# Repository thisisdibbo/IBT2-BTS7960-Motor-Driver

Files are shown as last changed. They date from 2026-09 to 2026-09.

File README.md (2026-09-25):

# IBT-2 High-Current H-Bridge Motor Driver (BTS7960B) — Custom PCB

<p align="center">
  
  
  
</p>

A custom-designed **IBT-2 style H-bridge motor driver** built around two Infineon **BTS7960B** high-current half-bridges and a **TI SN74HC244** input buffer. It drives one brushed DC motor in both directions, with PWM speed control from any microcontroller (Arduino, ESP32, STM32, …).

The board was designed in Autodesk EAGLE, then fabricated, assembled and bench-tested: **at full drive, the voltage across the motor terminals equals the supply voltage**, confirming that the H-bridge switches the full supply onto the load.

It also has a **built-in HAT circuit**: a red power LED, two green signal LEDs and a 4-pin JST connector that plugs straight into an Arduino shield PCB — see [Built-in HAT Circuit](#built-in-hat-circuit).

## Contents

- [Fabricated Board](#fabricated-board)
- [Schematic and PCB](#schematic-and-pcb)
- [Features](#features)
- [Built-in HAT Circuit](#built-in-hat-circuit)
- [How It Works](#how-it-works)
- [Pinout](#pinout)
- [Control Logic](#control-logic)
- [Quick Start (Arduino)](#quick-start-arduino)
- [Specifications](#specifications)
- [Test Results](#test-results)
- [Bill of Materials](#bill-of-materials)
- [Repository Structure](#repository-structure)
- [Limitations and Future Improvements](#limitations-and-future-improvements)
- [References](#references)
- [Author](#author)
- [License](#license)

---

## Fabricated Board

<!-- Put your two photos in the images/ folder with exactly these names: fabricated_1.jpg and fabricated_2.jpg -->
<p align="center">
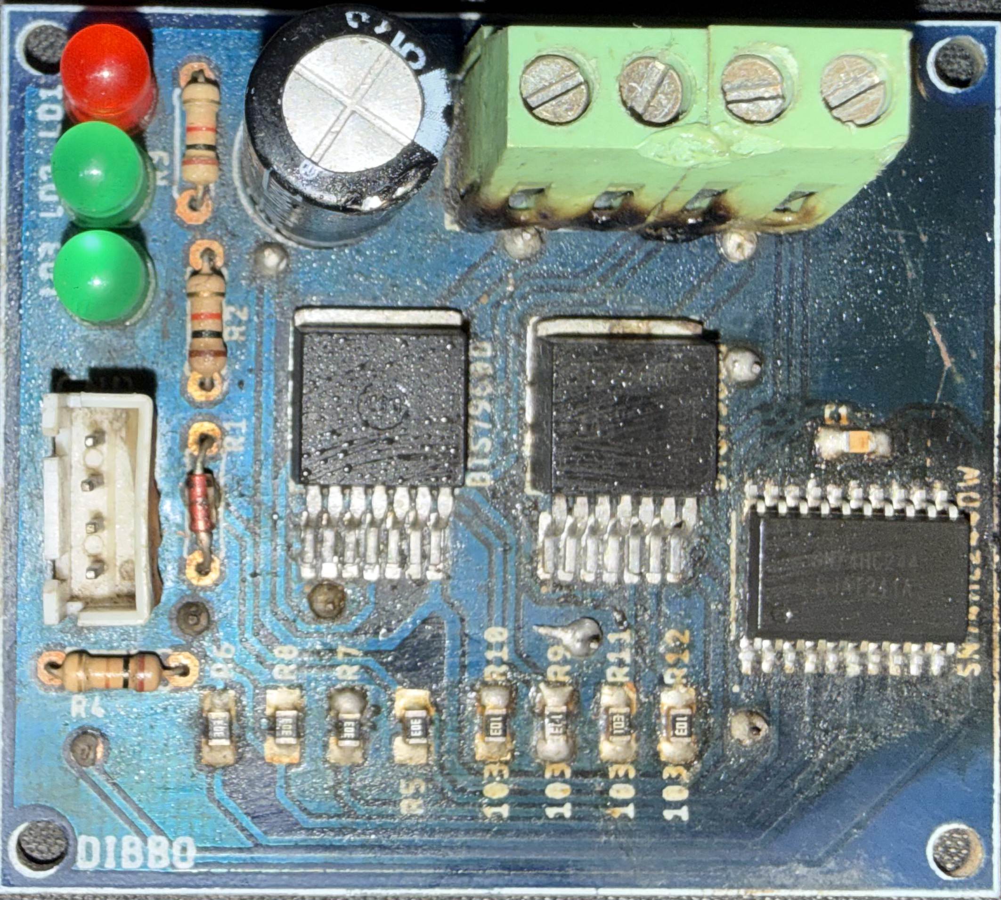
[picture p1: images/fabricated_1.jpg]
Fabricated IBT-2 board, photo 1
  
  &nbsp;&nbsp;
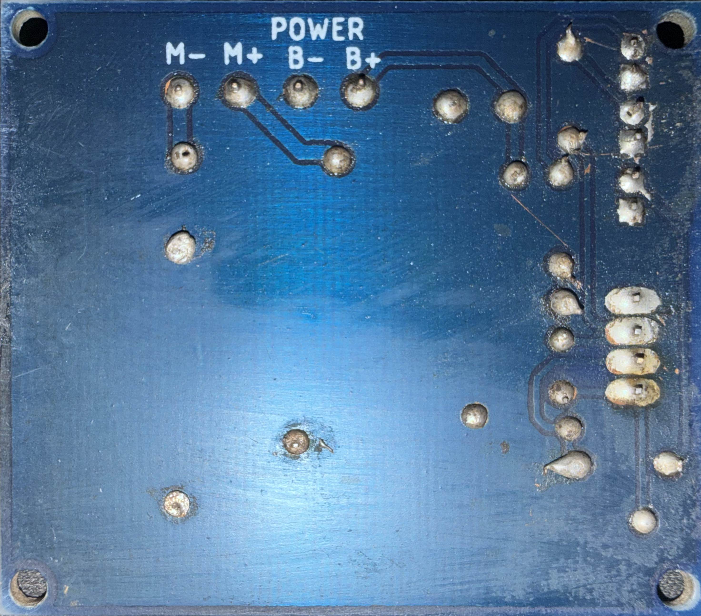
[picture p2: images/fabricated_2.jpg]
Fabricated IBT-2 board, photo 2
  
</p>
<p align="center"><em>The fabricated and assembled board</em></p>

## Schematic and PCB

<p align="center">
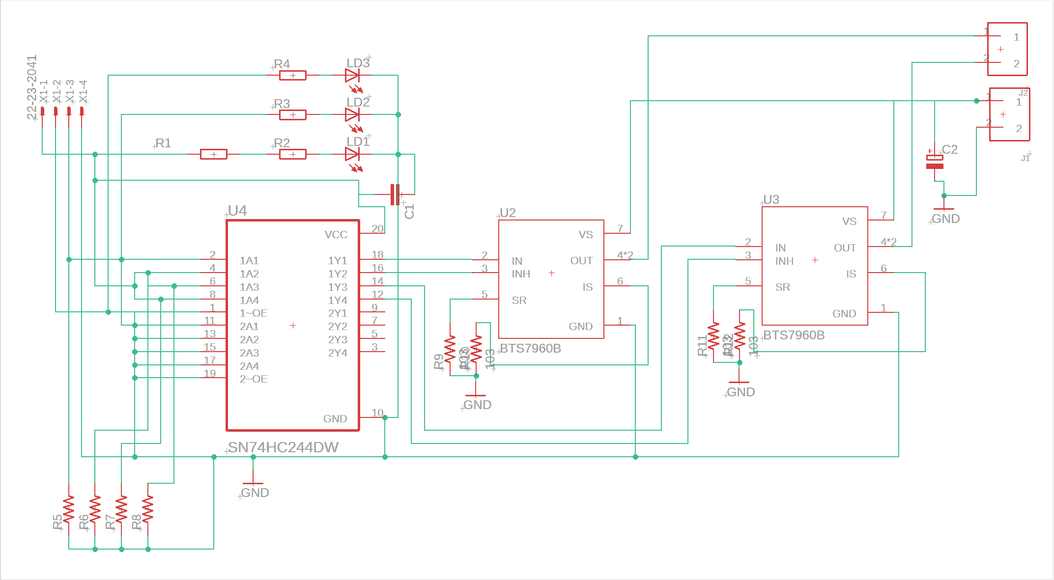
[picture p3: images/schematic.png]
Schematic of the IBT-2 motor driver
  
</p>
<p align="center"><em>Schematic — U4 buffers the inputs, U2 + U3 form the H-bridge, J1 = power in, J2 = motor out</em></p>

<p align="center">
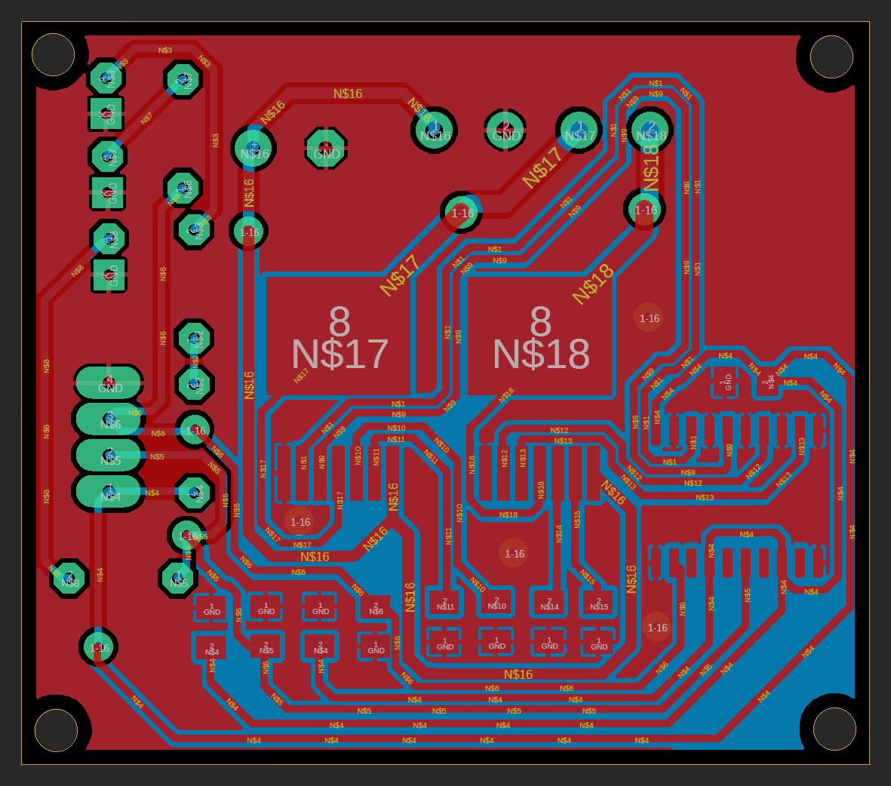
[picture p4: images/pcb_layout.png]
PCB layout of the IBT-2 motor driver
  
</p>
<p align="center"><em>PCB layout — 2 layers, 59.6 × 52.3 mm, red = top copper, blue = bottom copper, GND pour on both layers</em></p>

## Features

- **Full H-bridge** from two BTS7960B NovalithIC™ half-bridges (7 mΩ high-side + 9 mΩ low-side, typ.)
- **Buffered inputs** — an SN74HC244 sits between the microcontroller and the power stage
- **Only two control signals** (RPWM, LPWM) — both half-bridges are enabled automatically when logic power is present
- **Safe default state** — on-board 30 kΩ pull-downs hold RPWM/LPWM LOW if the MCU pins float (e.g. during reset), so the motor is held in brake instead of running
- **Built-in HAT circuit** — red power LED, two green signal LEDs and a 4-pin JST connector for direct connection to an Arduino shield PCB
- **Protection built into the BTS7960B** — current limitation, short-circuit and over-temperature shutdown, under-voltage shutdown, over-voltage lock-out
- **Adjustable slew rate** through the SR resistors (10 kΩ fitted)
- **Bulk capacitor** on the motor supply and a decoupling capacitor on the logic supply
- **5 mm screw terminals** for power and motor
- 4 × Ø3 mm mounting holes

## Built-in HAT Circuit

The logic side of the board is a small built-in **HAT circuit**: the driver plugs into an Arduino shield PCB with one cable, and its status can be read at a glance — no loose jumper wires.

| Part | Type | Function |
|:---:|:---|:---|
| LD1 | 🔴 Red LED, 3 mm | **Power ON** — lights when the logic supply (VCC) is present |
| R1 | Diode (on the R1 footprint) | **Reverse protection** — in series with the red power LED, protects the LED branch if VCC is connected backwards |
| LD2 | 🟢 Green LED, 3 mm | **RPWM signal** — lights when RPWM is HIGH (forward) |
| LD3 | 🟢 Green LED, 3 mm | **LPWM signal** — lights when LPWM is HIGH (reverse) |
| X1 | 4-pin JST connector | **Direct connection to the Arduino shield PCB** with a single JST cable (VCC, LPWM, RPWM, GND) |

The green LEDs are driven by the control signals themselves, so under PWM their brightness follows the duty cycle — direction and approximate speed are visible at a glance.

## How It Works

```mermaid
flowchart LR
    MCU["Arduino shield PCB<br/>or any MCU"] -->|RPWM, LPWM| X1["HAT circuit<br/>JST connector + LEDs"]
    X1 --> BUF["U4 · SN74HC244<br/>input buffer"]
    BUF -->|IN, INH| U2["U2 · BTS7960B<br/>half-bridge A"]
    BUF -->|IN, INH| U3["U3 · BTS7960B<br/>half-bridge B"]
    PSU["Motor supply<br/>B+ / B−"] --> U2
    PSU --> U3
    U2 -->|M+| MOT(("DC<br/>motor"))
    U3 -->|M−| MOT
```

- **Power stage** — each BTS7960B contains a high-side P-MOSFET, a low-side N-MOSFET and a gate driver with built-in dead-time. With INH HIGH, `IN = HIGH` connects the output to B+ and `IN = LOW` connects it to GND; INH LOW puts the chip to sleep. U2 drives **M+**, U3 drives **M−**, and the motor sits between them.
- **Input stage** — U4 buffers RPWM → U2 `IN` and LPWM → U3 `IN`. Two more U4 channels (1A2, 1A4) are tied to VCC, so both `INH` pins go HIGH as soon as logic power is applied. The unused second half of U4 has its inputs and output-enable tied to GND so nothing floats.
- **Slew rate and current sense** — R9/R11 (10 kΩ, SR → GND) give a moderate switching slew rate. The IS (current-sense / fault) pins are terminated with R10/R12 (10 kΩ) to GND and are not routed to the header in this revision.
- **Supply** — C2 (330 µF) is the bulk capacitor on B+, C1 (100 nF) decouples U4. A diode on the R1 footprint sits in series with the power-LED branch (X1-1 → R1 → R2 → LD1). Logic ground and power ground are the same net.

## Pinout

> The **B+ B− M+ M−** labels are printed on the **bottom** silkscreen. On X1, pin 4 (GND) is next to the **GND** mark on the top silkscreen.

### X1 — JST logic connector (4-pin, to the Arduino shield)

| Pin | Signal | Description |
|:---:|:---|:---|
| 1 | **VCC** | Logic supply for U4 — 5 V (or 3.3 V for 3.3 V MCUs). Also enables both half-bridges; red LED LD1 lights. |
| 2 | **LPWM** | Drives U3 → **M−**. HIGH = M− to B+, LOW = M− to GND. Green LED: LD3 |
| 3 | **RPWM** | Drives U2 → **M+**. HIGH = M+ to B+, LOW = M+ to GND. Green LED: LD2 |
| 4 | **GND** | Ground (same net as B−) |

### J1 — Power input (2-pin screw terminal, 5 mm)

| Pin | Label | Description |
|:---:|:---:|:---|
| 1 | **B+** | Motor supply V<sub>S</sub>, 5.5 – 27.5 V |
| 2 | **B−** | Supply ground |

### J2 — Motor output (2-pin screw terminal, 5 mm)

| Pin | Label | Description |
|:---:|:---:|:---|
| 1 | **M+** | Output of U2 (controlled by RPWM) |
| 2 | **M−** | Output of U3 (controlled by LPWM) |

> **Wiring:** always connect the microcontroller GND to X1-4. B− and X1-4 are the same ground.

## Control Logic

Both half-bridges are enabled whenever VCC is present (INH = HIGH).

| RPWM (X1-3) | LPWM (X1-2) | M+ | M− | Motor |
|:---:|:---:|:---:|:---:|:---|
| HIGH | LOW | B+ | GND | Forward, full speed (V<sub>out</sub> ≈ V<sub>in</sub>) |
| LOW | HIGH | GND | B+ | Reverse, full speed |
| PWM | LOW | PWM | GND | Forward, speed ∝ duty cycle |
| LOW | PWM | GND | PWM | Reverse, speed ∝ duty cycle |
| LOW | LOW | GND | GND | Brake (both low-side switches on) — also the default when the inputs float |
| HIGH | HIGH | B+ | B+ | Brake (both high-side switches on) |

> Bring the motor to a stop (both inputs LOW) before reversing direction.

## Quick Start (Arduino)

Plug the JST cable from the Arduino shield PCB into X1, or wire the pins directly:

| Driver | Connect to |
|:---|:---|
| X1-1 VCC | Arduino **5V** |
| X1-2 LPWM | Arduino **D6** |
| X1-3 RPWM | Arduino **D5** |
| X1-4 GND | Arduino **GND** |
| J1 B+ / B− | Motor power supply + / − |
| J2 M+ / M− | DC motor |

```cpp
// IBT-2 (BTS7960B) custom driver — bidirectional test
const uint8_t RPWM = 5;   // X1-3 -> M+
const uint8_t LPWM = 6;   // X1-2 -> M-

// speed: -255 (full reverse) ... 0 (brake) ... +255 (full forward)
void setMotor(int speed) {
  speed = constrain(speed, -255, 255);
  if (speed >= 0) {
    analogWrite(LPWM, 0);
    analogWrite(RPWM, speed);
  } else {
    analogWrite(RPWM, 0);
    analogWrite(LPWM, -speed);
  }
}

void setup() {
  pinMode(RPWM, OUTPUT);
  pinMode(LPWM, OUTPUT);
  setMotor(0);
}

void loop() {
  setMotor(255);  delay(2000);   // full forward: V(M+ - M-) ≈ +V_in
  setMotor(0);    delay(1000);   // brake
  setMotor(-255); delay(2000);   // full reverse: V(M+ - M-) ≈ -V_in
  setMotor(0);    delay(1000);
  setMotor(128);  delay(2000);   // about 50 % speed forward
  setMotor(0);    delay(1000);
}
```

**Notes**

- **3.3 V boards (ESP32, STM32, Pico):** power X1-1 (VCC) from **3.3 V**, not 5 V. With VCC = 5 V the 74HC244 needs about 3.5 V for a logic HIGH, which a 3.3 V pin may not reach reliably. The BTS7960B inputs only need ≥ 2.15 V, so 3.3 V logic is enough. *(3.3 V operation follows from the datasheets; not yet tested on this board.)*
- **Never power VCC above 5.3 V** — U4 passes VCC straight to the BTS7960B `IN`/`INH` pins, whose absolute maximum is 5.3 V.
- Arduino Uno PWM on D5/D6 runs at about 980 Hz, which can make the motor whine. The BTS7960B supports PWM up to 25 kHz.

## Specifications

| Parameter | Value |
|:---|:---|
| Motor supply V<sub>S</sub> (B+) | 5.5 – 27.5 V (BTS7960B operating range; undervoltage shutdown at 4.0 – 5.4 V, over-voltage lock-out at 27.6 – 30 V) |
| Logic supply (VCC) | 5 V nominal, 3.3 V for 3.3 V MCUs — max 5.3 V |
| Control inputs | RPWM, LPWM — active HIGH, 30 kΩ pull-down on each |
| Interface (HAT circuit) | 4-pin JST connector · red power LED · 2 green signal LEDs |
| PWM frequency | Up to 25 kHz |
| Switch on-resistance | 7 mΩ high-side + 9 mΩ low-side (typ. at 25 °C) → 16 mΩ path resistance |
| IC current limit | 43 A typ. — *board current is limited by the copper, see [Limitations](#limitations-and-future-improvements)* |
| Protection | Current limitation, short-circuit, over-temperature (latched), under-/over-voltage |
| PCB | 2 layers, 59.6 × 52.3 mm, 35 µm (1 oz) copper, GND pour on top and bottom |
| Trace widths | Signals 0.51 mm · V<sub>S</sub> 0.76–0.81 mm · motor outputs 1.27 mm |
| Mounting | 4 × Ø3.0 mm holes |
| Design tool | Autodesk EAGLE 9.6.2 |

## Test Results

| Test | Condition | Result |
|:---|:---|:---|
| Output voltage at full drive | Motor supply on B+/B−, logic powered, one input HIGH and the other LOW | V<sub>M+ − M−</sub> = V<sub>in</sub> ✅ |

<!-- Add your measured numbers here, e.g. "12.0 V in -> 12.0 V out", plus the motor or load used. -->

The output matched the supply, which means the high-side switch of one BTS7960B and the low-side switch of the other are fully on. The only loss is the typical 16 mΩ path resistance (≈ 16 mV per amp of motor current).

## Bill of Materials

| Ref | Qty | Value / Part | Package | Function |
|:---|:---:|:---|:---|:---|
| U2, U3 | 2 | Infineon **BTS7960B** | P-TO-263-7 | High-current half-bridge |
| U4 | 1 | TI **SN74HC244DW** | SOIC-20 (wide) | Octal buffer, input stage |
| R9, R11 | 2 | 10 kΩ (103) | 1206 | Slew-rate resistor, SR → GND |
| R10, R12 | 2 | 10 kΩ (103) | 1206 | Current-sense load, IS → GND |
| R5, R8 | 2 | 30 kΩ (303) | 1206 | Pull-downs on RPWM / LPWM |
| R6, R7 | 2 | 30 kΩ (303) | 1206 | Pull-downs on U4 enable inputs (tied to VCC in this revision, so optional) |
| R1 | 1 | Diode (fitted on the R1 footprint) | THT, 7.62 mm pitch | Reverse-polarity protection for the power-LED branch (X1-1 → R1 → R2 → LD1) |
| R2, R3, R4 | 3 | 1 kΩ | THT 0207, 7.62 mm pitch | LED series resistors: R2 → LD1 (red), R3 → LD2 (green), R4 → LD3 (green) |
| LD1 | 1 | Red LED, 3 mm | THT | Power indicator (HAT circuit) |
| LD2, LD3 | 2 | Green LED, 3 mm | THT | RPWM / LPWM signal indicators (HAT circuit) |
| C1 | 1 | 100 nF ceramic (X7R, ≥ 16 V) | 1206 | U4 supply decoupling |
| C2 | 1 | 330 µF electrolytic | Radial, 5 mm pitch, up to Ø10 mm | Motor-supply bulk capacitor — voltage rating must be above B+ (e.g. 35 V for a 24 V supply) |
| X1 | 1 | 4-pin JST connector | 2.54 mm pitch (Molex 22-23-2041 footprint) | Logic connector to the Arduino shield (HAT circuit) |
| J1, J2 | 2 | 2-pin PCB screw terminal | 5 mm pitch | Power input / motor output |

> The BTS7960B is listed as obsolete by major distributors (e.g. DigiKey) — check availability before building one.

## Repository Structure

```
IBT2-BTS7960-Motor-Driver/
├── hardware/
│   ├── IBT2_BTS7960.sch            # EAGLE schematic
│   ├── IBT2_BTS7960.brd            # EAGLE board layout
│   └── IBT2_BTS7960.dxf            # DXF export (top copper, pads, vias, outline)
├── fabrication/
│   ├── board_print_2025-07-05.pdf  # 1:1 board print, A4
│   └── board_print_2025-07-06.pdf  # 1:1 board print, A4
├── images/
│   ├── schematic.png
│   ├── pcb_layout.png
│   ├── fabricated_1.jpg
│   └── fabricated_2.jpg
├── LICENSE
└── README.md
```

Open the `.sch` / `.brd` pair in **Autodesk EAGLE 9.x** or **Autodesk Fusion Electronics**; KiCad can also import EAGLE projects. Keep both files in the same folder with the same name so the schematic and board stay linked.

## Limitations and Future Improvements

**Current capability.** The BTS7960B itself handles tens of amps, but on this PCB the motor current flows through 0.76 mm (V<sub>S</sub>) and 1.27 mm (output) traces on 1 oz copper, with single vias where the power paths change layers. A rough IPC-2221 estimate puts the V<sub>S</sub> trace at about **2 – 2.7 A continuous** (10 – 20 °C temperature rise). Use it with small-to-medium motors and check the trace temperature before running higher currents.

**Fault reset.** Because `INH` is tied HIGH through U4, a latched over-temperature or short-circuit shutdown is cleared by power-cycling VCC (this pulls `INH` LOW).

Planned for the next revision:

- [ ] Replace the V<sub>S</sub> and output traces with wide copper pours and stitching vias; add more copper under the BTS7960B tabs, or a heatsink
- [ ] Add a 470 nF ceramic capacitor from V<sub>S</sub> to GND next to each BTS7960B (recommended in the datasheet)
- [ ] Bring R_IS / L_IS (current sense and fault flag) to the header, with R<sub>IS</sub> ≈ 1 kΩ (≈ 1 V per 8.5 A)
- [ ] Bring R_EN / L_EN to the header so the MCU can disable the bridge and reset faults
- [ ] Add reverse-polarity protection on B+
- [ ] Move the reverse-protection diode (now on the R1 footprint) in series with the whole VCC input — today it protects only the power-LED branch, because U4 takes VCC directly from X1-1 (a Schottky diode keeps the drop low)

## References

- [Infineon BTS7960 datasheet](https://www.infineon.com/dgdl/Infineon-BTS7960-DS-v01_01-en.pdf)
- [TI SN74HC244 product page and datasheet](https://www.ti.com/product/SN74HC244)

## Author

**Md. Mahin Rahman** — [@thisisdibbo](https://github.com/thisisdibbo) · [mr.d2003feb@gmail.com](mailto:mr.d2003feb@gmail.com)<br>
Department of Electrical and Electronic Engineering, Islamic University of Technology (IUT), Gazipur, Bangladesh

## License

Released under the [MIT License](LICENSE).

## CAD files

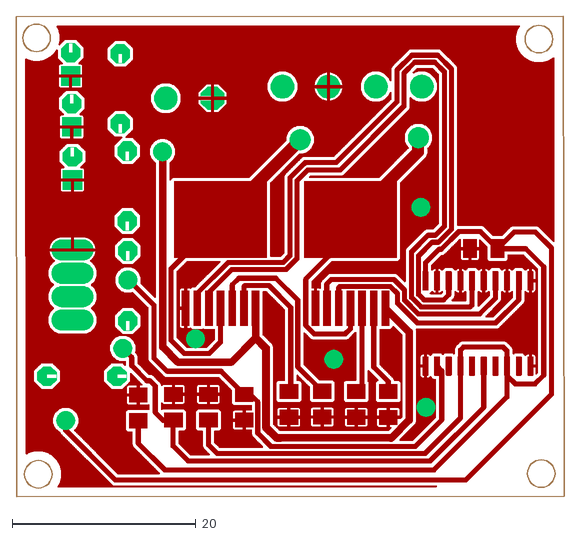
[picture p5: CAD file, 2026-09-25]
hardware/IBT2_BTS7960.dxf
59.6 x 52.3

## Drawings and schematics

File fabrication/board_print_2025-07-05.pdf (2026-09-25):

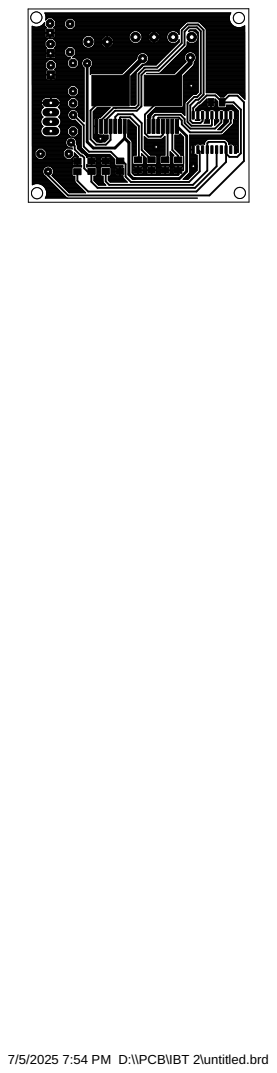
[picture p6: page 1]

7/5/2025 7:54 PM D:\\PCB\IBT 2\untitled.brd

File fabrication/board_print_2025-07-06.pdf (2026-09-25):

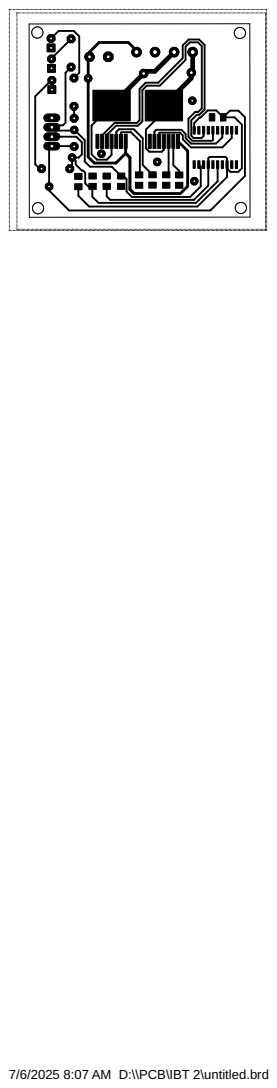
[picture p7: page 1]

7/6/2025 8:07 AM D:\\PCB\IBT 2\untitled.brd

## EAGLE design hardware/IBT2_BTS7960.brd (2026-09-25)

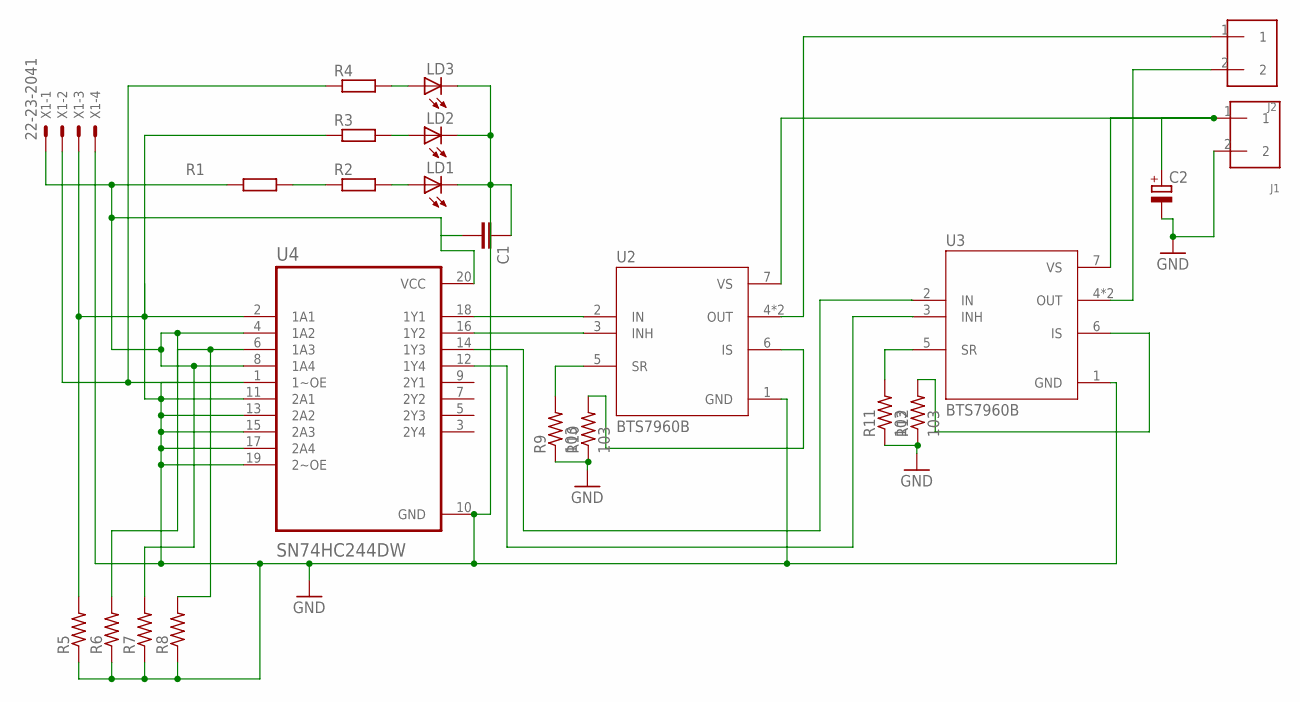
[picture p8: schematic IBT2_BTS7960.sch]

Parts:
C1: C-EUC1206K; C1206K
C2: CPOL-EUE5-10.5; E5-10,5
J1, J2: SCREW_TERMINAL; PHEONIX-1935161
LD1, LD2, LD3: LED3MM
R1, R2, R3, R4: R-EU_0207/7; 0207/7
R5, R6, R7, R8: R-US_M1206; M1206
R9, R10, R11, R12: 103; M1206
U2, U3: BTS7960B; DPAK127P1490X440-8N
U4: SN74HC244DW; SOIC127P1030X265-20N
X1: 22-23-2041

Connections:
GND: C1.1, C2.-, J1.2, LD1.K (C), LD2.K (C), LD3.K (C), R5.1, R6.1, R7.1, R8.1, R9.1, R10.1, R11.1, R12.1, U2.1 (GND), U3.1 (GND), U4.1 (1~OE), U4.10 (GND), U4.11 (2A1), U4.13 (2A2), U4.15 (2A3), U4.17 (2A4), U4.19 (2~OE), X1.4
unnamed: U2.2 (IN), U4.18 (1Y1)
unnamed: R1.2, R2.1
unnamed: LD1.A, R2.2
unnamed: C1.2, R1.1, R6.2, R7.2, U4.4 (1A2), U4.8 (1A4), U4.20 (VCC), X1.1
unnamed: R4.1, R8.2, U4.6 (1A3), X1.2
unnamed: R3.1, R5.2, U4.2 (1A1), X1.3
unnamed: LD2.A, R3.2
unnamed: LD3.A, R4.2
unnamed: U2.3 (INH), U4.16 (1Y2)
unnamed: R9.2, U2.5 (SR)
unnamed: R10.2, U2.6 (IS)
unnamed: U3.2 (IN), U4.14 (1Y3)
unnamed: U3.3 (INH), U4.12 (1Y4)
unnamed: R11.2, U3.5 (SR)
unnamed: R12.2, U3.6 (IS)
unnamed: C2.+, J1.1, U2.7 (VS), U3.7 (VS)
unnamed: J2.1, U2.4 (OUT), U2.8 (OUT)
unnamed: J2.2, U3.4 (OUT), U3.8 (OUT)

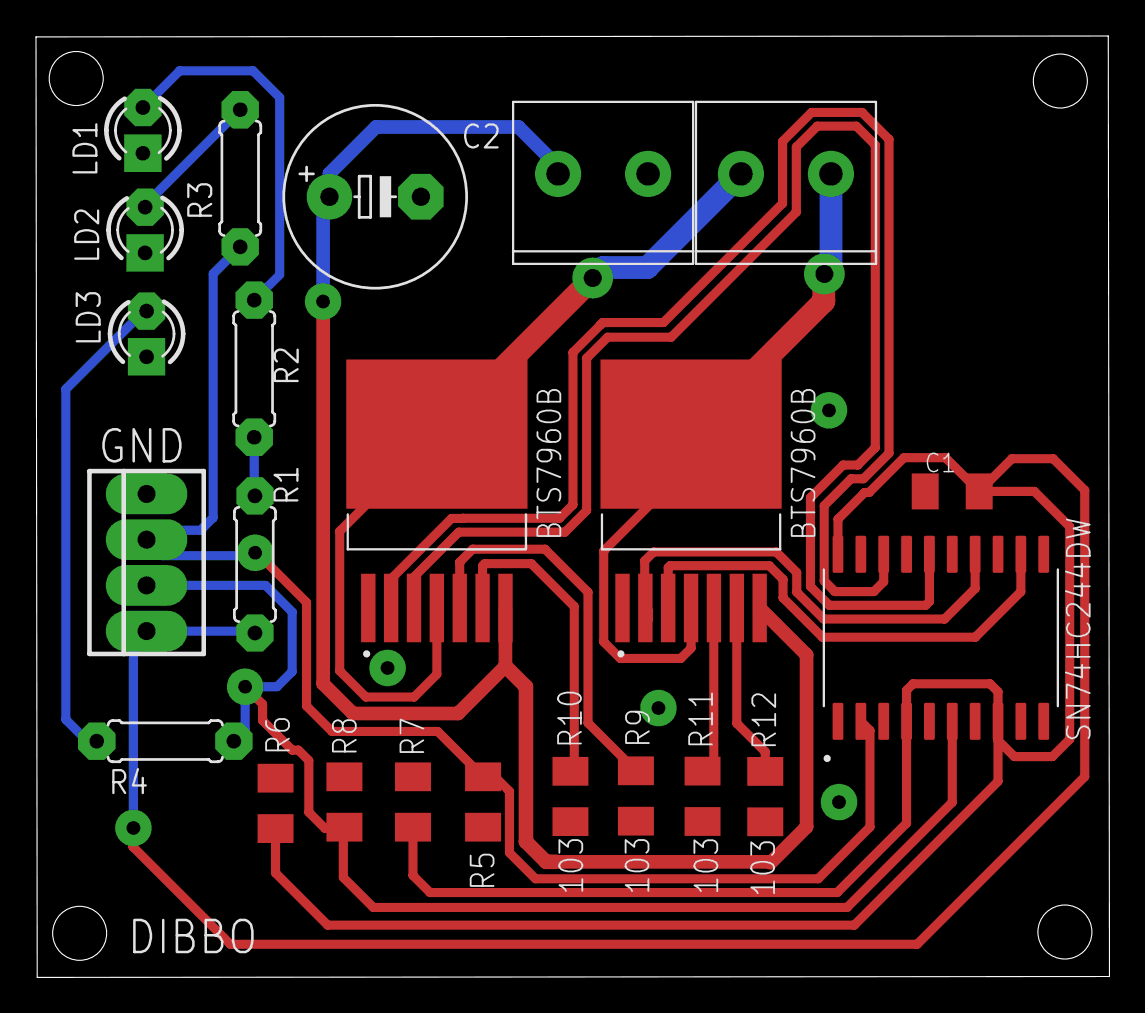
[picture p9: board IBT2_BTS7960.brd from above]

Board: 2 copper layers, 59.6 x 52.3 mm, 23 parts (0 on the bottom side), 19 nets.

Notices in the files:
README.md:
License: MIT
